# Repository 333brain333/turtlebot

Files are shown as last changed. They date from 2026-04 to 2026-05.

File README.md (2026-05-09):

# Turtlebot

|**Общий вид**|**Внутри робота**|**Вид снизу**|
|---|---|---|
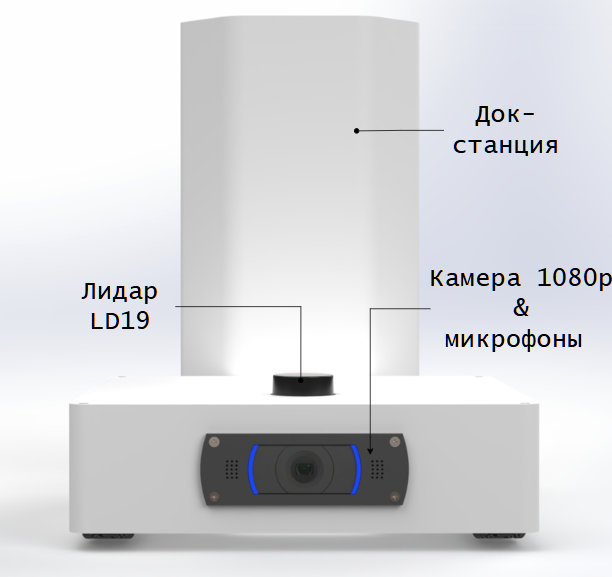
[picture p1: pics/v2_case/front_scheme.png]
Robot front view
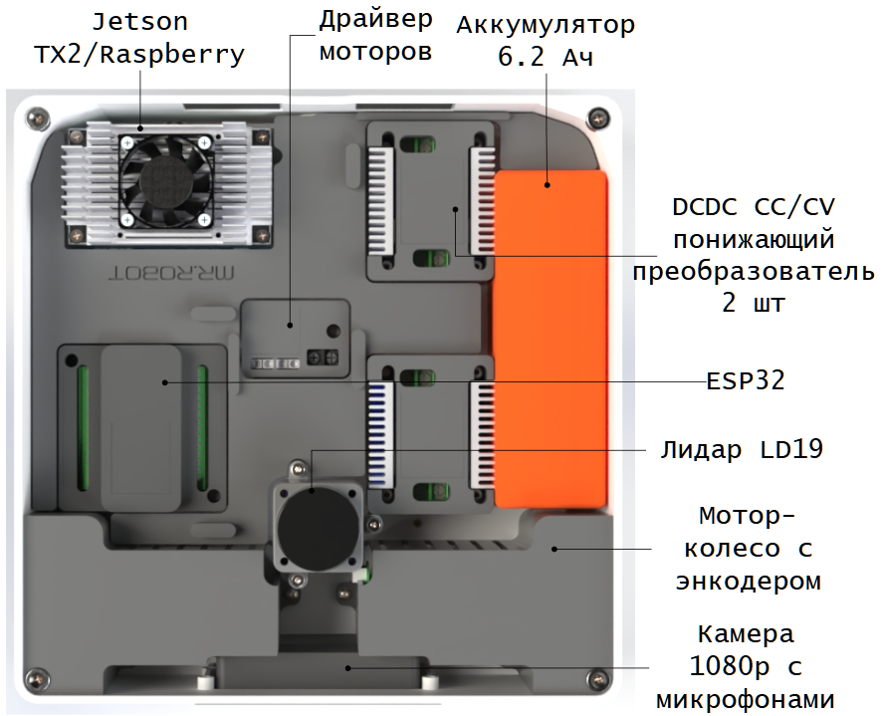
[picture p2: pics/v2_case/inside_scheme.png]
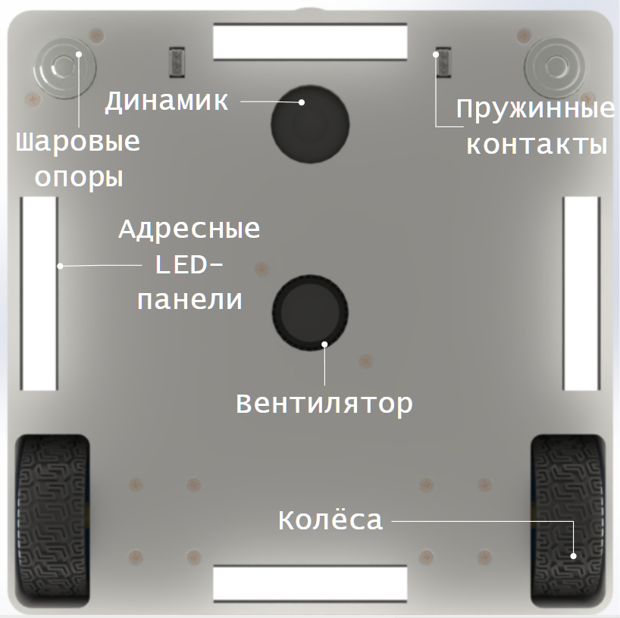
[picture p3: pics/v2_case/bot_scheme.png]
||||

Разработка 2х колёсного робота по типу turtlebot. [В рамках курса ROS2 — Введение в робототехнику](https://stepik.org/course/221157/promo#toc)  

# Wiki
В [Wiki](https://github.com/333brain333/turtlebot/wiki) репозитория находятся схемы соединения, перечень компонентов, 3D модели, etc.

(https://333brain333.github.io/turtle-rex-runner/)

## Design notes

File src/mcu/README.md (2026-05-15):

# MCU UART2 Interface

Описание интерфейса взаимодействия с микроконтроллером по UART2 на ESP32.

## Аппаратная часть

- UART: `Serial2`
- Baudrate: `115200`
- Формат: `8N1`
- RX: пин `16`
- TX: пин `17`
- Окончание команды: `\n` (перевод строки)

> Команды отправляются текстом, разделяя параметры пробелом.

При старте микроконтроллер дважды мигает адресной лентой: `0.5 с` включено, `0.5 с` выключено, `0.5 с` включено, затем оставляет ленту выключенной.

## Общая схема команды

Каждая команда начинается с ключевого слова и может содержать параметры:

```text
COMMAND_NAME param1 param2 ...
```

Пример:

```text
SET_LED 255 black
```

## Поддерживаемые команды

### `SET_PWM leftA leftB rightA rightB`

Управление ШИМ для моторов. Все значения в диапазоне `0..255`.

- `leftA` – ШИМ для `LEFT_MOTOR_A`
- `leftB` – ШИМ для `LEFT_MOTOR_B`
- `rightA` – ШИМ для `RIGHT_MOTOR_A`
- `rightB` – ШИМ для `RIGHT_MOTOR_B`

Пример:

```text
SET_PWM 0 200 0 200
```

### `SET_POSE x y theta`

Установить текущие координаты и угол робота.

- `x` – позиция по оси X
- `y` – позиция по оси Y
- `theta` – угол в радианах или градусах в зависимости от вашего применения

Пример:

```text
SET_POSE 10.5 20.0 1.57
```

### `SET_WHEELS_SPEED leftSpeed rightSpeed`

Задать целевую скорость колёс в мм/с.

- `leftSpeed` – целевая скорость левого колеса
- `rightSpeed` – целевая скорость правого колеса

Пример:

```text
SET_WHEELS_SPEED 100 100
```

### `SET_COEFF Kp Ki Kd Kff`

Обновить PID‑коэффициенты для регулировки скорости.

- `Kp` – пропорциональный
- `Ki` – интегральный
- `Kd` – дифференциальный
- `Kff` – форвард-фидбек

Пример:

```text
SET_COEFF 1.2 1.4 0.02 0.3
```

### `SET_LED brightness color`

Управление светодиодной лентой по всей длине.

- `brightness` – яркость `0..255`
- `color` – название цвета

Поддерживаемые цвета:

- `black` / `off`
- `white`
- `red`
- `green`
- `blue`
- `yellow`
- `cyan`
- `magenta`
- `orange`
- `purple`

Пример:

```text
SET_LED 255 black
SET_LED 128 red
SET_LED 200 blue
```

### `SHUTDOWN`

Выключить светодиодную ленту и отключить дальнейшую подачу ШИМ на драйвер колёс до перезапуска микроконтроллера.

Пример:

```text
SHUTDOWN
```

Ответ:

```text
OK: Shutdown
```

### `I2C_SCAN`

Вывести найденные I2C-адреса. Полезно для проверки INA226 на шине.

Пример:

```text
I2C_SCAN
```

Примеры ответов:

```text
I2C_SCAN 0x40
I2C_SCAN none
```

Для INA226 обычно ожидается адрес `0x40`.

### `INA226_DEBUG`

Вывести состояние INA226 и сырые значения основных регистров.

Пример:

```text
INA226_DEBUG
```

Пример ответа:

```text
INA226_DEBUG sda=21 scl=22 addr=0x40 available=1 probe_0x40=0 cfg=1:0x4527 bus=1:9876 shunt=1:120 mfg=1:0x5449 die=1:0x2260
```

Полезные поля:

- `sda` / `scl` — пины I2C на ESP32
- `available` — найден ли INA226 прошивкой
- `probe_0x40=0` — устройство ответило на адрес `0x40`
- `probe_0x40=2` — устройство не ответило на адрес `0x40`
- `bus` — сырое значение регистра напряжения
- `shunt` — сырое значение регистра шунта

## Ответы от микроконтроллера

Устройство отвечает строками вида:

- `OK: ...` — команда принята и выполнена
- `ERROR: ...` — команда неправильно сформирована или неизвестна

Примеры:

```text
OK: LED updated
ERROR: Unknown command
```

## Текущая телеметрия

Каждые ~100 мс микроконтроллер отправляет статус:

```text
POS X=... Y=... Th=... ENC L=... R=... SPD L=... mm/s R=... mm/s PWR V=... I=... A
```

Это полезно для отладки положения, энкодеров, скорости, напряжения и тока питания.

Поля питания:

- `PWR V` — напряжение шины, измеренное INA226, в вольтах
- `PWR I` — ток через шунт `0.01 Ом`, в амперах
- `PWR V=nan I=nan` — INA226 не найден или чтение по I2C не удалось

## Советы

- Отправляйте команды с `\n` в конце.
- Лучше сначала проверить ответ `OK`.
- Если команда возвращает `ERROR`, проверьте пробелы и порядок параметров.

## Быстрый пример взаимодействия

```text
SET_LED 255 blue
SET_WHEELS_SPEED 120 120
SET_COEFF 1.1 1.3 0.01 0.25
```

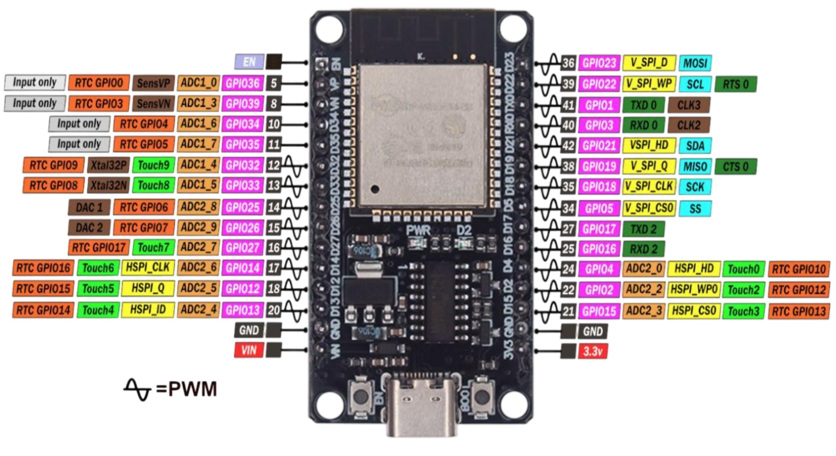
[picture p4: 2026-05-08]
pics/devices/esp32_pinout.jpg

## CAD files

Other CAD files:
3d_models/turtlebot_tx2.SLDASM
3d_models/turtlebot_nx.SLDASM

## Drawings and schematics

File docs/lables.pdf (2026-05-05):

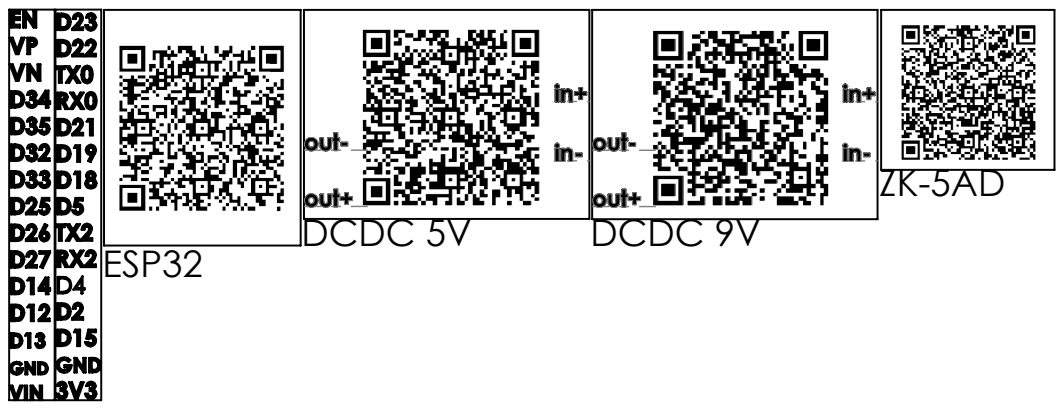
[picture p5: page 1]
DCDC 5V; DCDC 9V; МАСШТАБ:2:1; ЛИСТ 1 ИЗ 1; НЕ МАСШТАБИРОВАТЬ ЧЕРТЕЖ; РЕДАКЦИЯ; ЗАУСЕНЦЫ И ОСТРЫЕ КРОМКИ; ПО УМОЛЧАНИЮ:; ОБРАБОТКА:; РАЗМЕРЫ В МИЛЛИМЕТРАХ

ИМЯ | ПОДПИСЬ | ДАТА | | | | НАЗВАНИЕ:
Т.контр | | | | МАТЕРИАЛ: | ЧЕРТЕЖ №: этикетки МАССА: | A4

Разраб.
Пров.
Утв.
Маш.

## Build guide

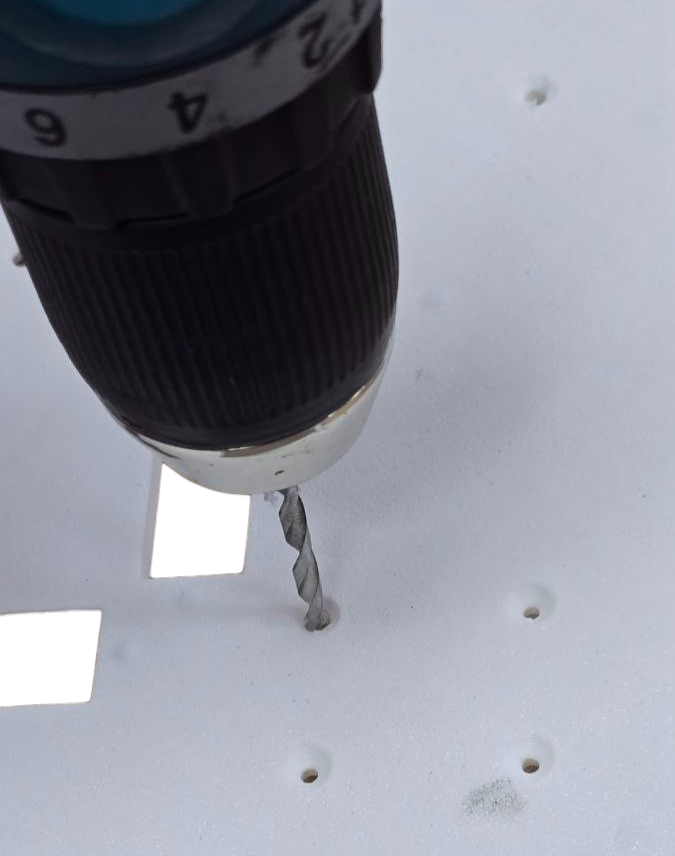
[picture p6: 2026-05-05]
pics/v2_case/assembly/drill.png

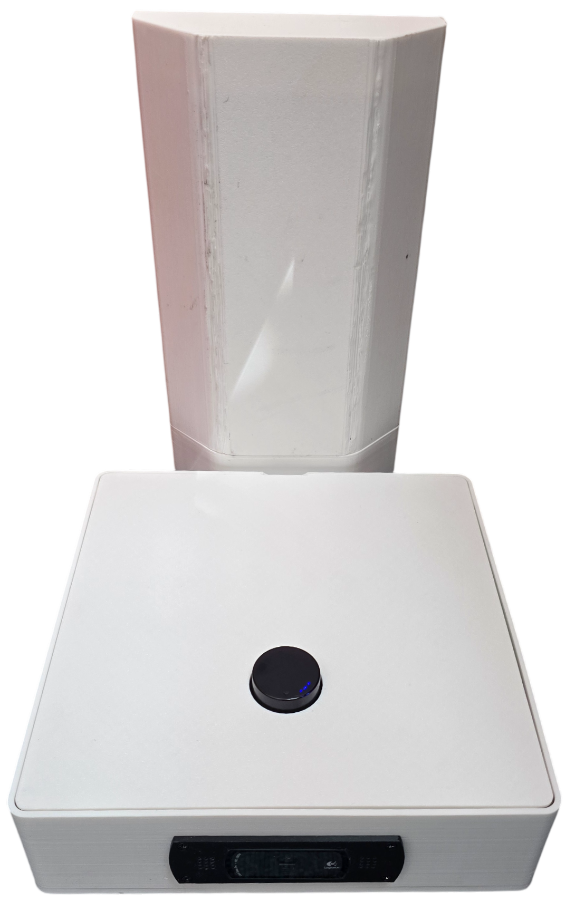
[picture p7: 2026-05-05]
pics/v2_case/assembly/doc_front.png

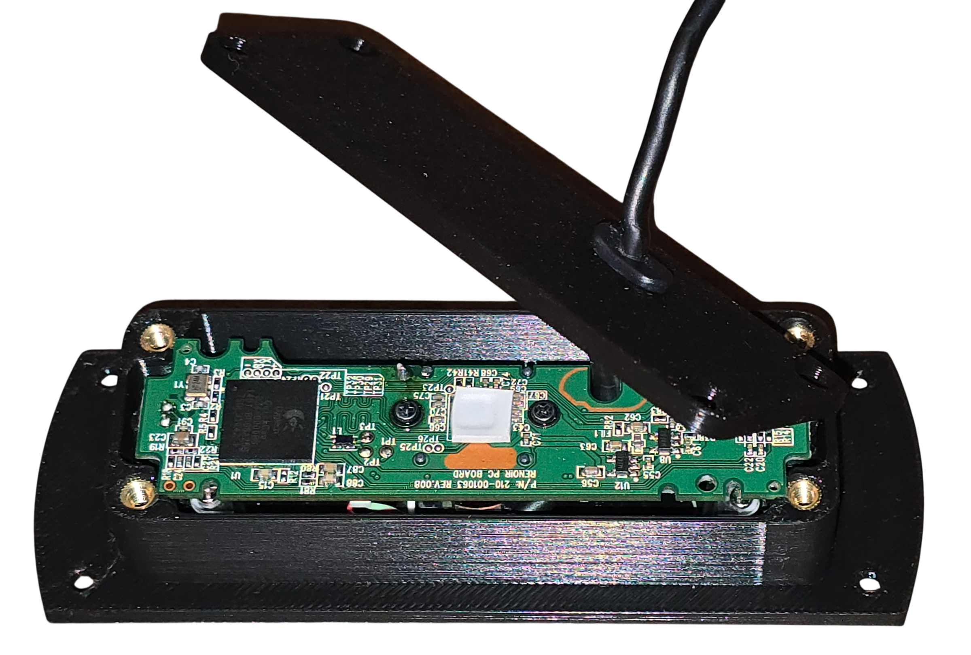
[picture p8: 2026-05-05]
pics/v2_case/assembly/cam_.png

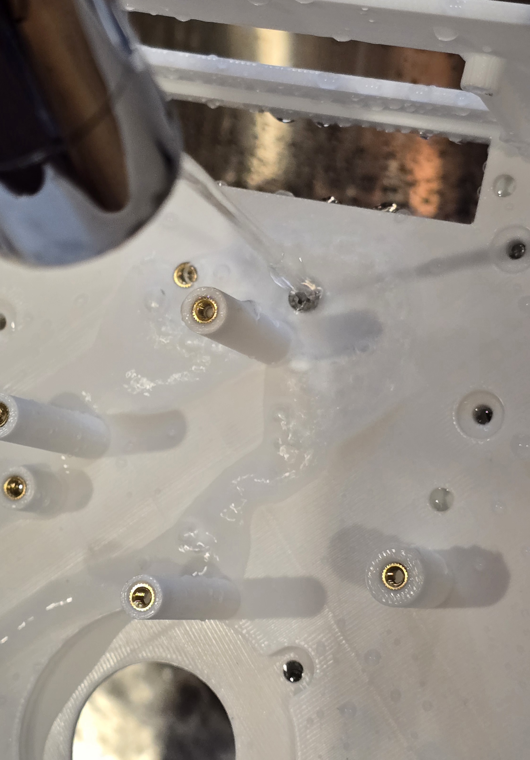
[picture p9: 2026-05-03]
pics/v2_case/assembly/cool.jpg

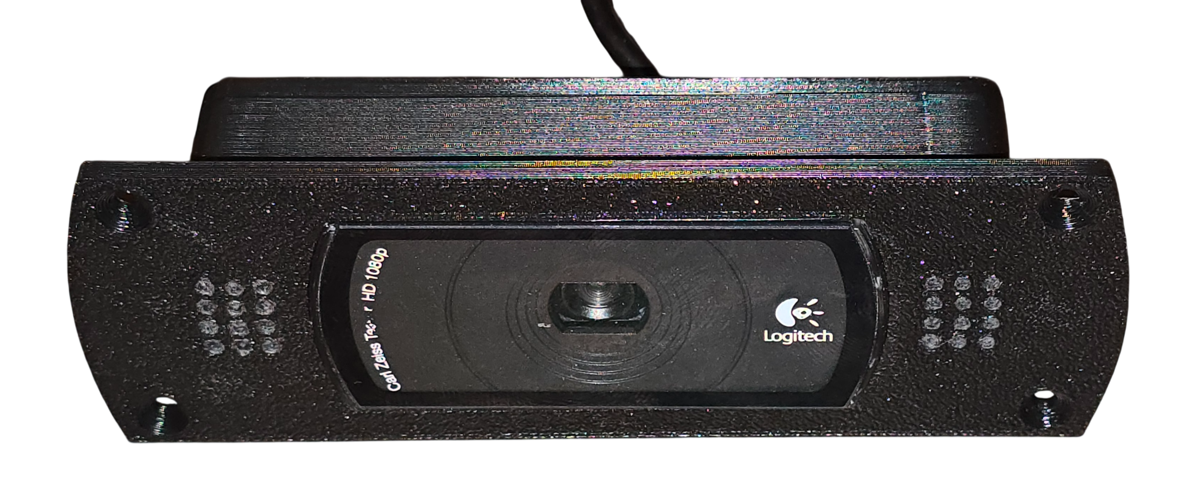
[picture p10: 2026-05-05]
pics/v2_case/assembly/cam_ass.png

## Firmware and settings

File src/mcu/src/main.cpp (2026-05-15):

#include <Arduino.h>
#include "main.h"
#include <FastLED.h>
#include <Wire.h>

#define LED_STRIP_PIN 13       // Пин подключения ленты к ESP32
#define NUM_LEDS    32          // Количество светодиодов в ленте
#define BRIGHTNESS  255          // Яркость (0-255)
#define LED_TYPE    WS2812B     // Тип светодиодной ленты
#define COLOR_ORDER GRB         // Порядок цветов (для WS2812B обычно GRB)

#define LEFT_MOTOR_A 14     // Цифровой выход (левый мотор). Если 0 - едем вперед
#define LEFT_MOTOR_B 27     // Цифровой выход (левый мотор). Если 0 - едем назад
#define RIGHT_MOTOR_A 25    // Цифровой выход (правый мотор). Если 0 - едем вперед
#define RIGHT_MOTOR_B 26    // Цифровой выход (правый мотор). Если 0 - едем назад

#define LED_BUILTIN_PIN 2       // Встроенный светодиод на ESP32 Dev Board

#define LEFT_ENCODER_A 33    // Цифровой вход, канал A энкодера левого колеса
#define LEFT_ENCODER_B 32    // Цифровой вход, канал B энкодера левого колеса 
#define RIGHT_ENCODER_A 34   // Цифровой вход, канал A энкодера правого колеса
#define RIGHT_ENCODER_B 35   // Цифровой вход, канал B энкодера правого колеса

#define JETSON_UART_RX 16     // RX2: прием данных от Jetson TX
#define JETSON_UART_TX 17     // TX2: передача данных на Jetson RX
#define JETSON_UART_BAUD 115200


/*
  * Константы для работы с INA226:
  * - INA226_I2C_SDA и INA226_I2C_SCL определяют пины для I2C шины, к которой подключён датчик.
  * - INA226_I2C_ADDRESS — стандартный адрес устройства на шине I2C (может быть изменён в зависимости от конкретной платы).
  * - INA226_SHUNT_OHMS — сопротивление шунта в Омах, используемое для расчёта тока по измеренному напряжению на шунте.
  *
  * Регистры:
  * - INA226_REG_CONFIG — регистр конфигурации, который нужно настроить для правильной работы датчика.
  * - INA226_REG_SHUNT_VOLTAGE — регистр, в котором хранится измеренное напряжение на шунте (для расчёта тока).
  * - INA226_REG_BUS_VOLTAGE — регистр, в котором хранится измеренное напряжение питания (для расчёта мощности).
  * - INA226_REG_MANUFACTURER_ID и INA226_REG_DIE_ID — служебные регистры для идентификации устройства.
*/
#define INA226_I2C_SDA 21
#define INA226_I2C_SCL 22
#define INA226_I2C_ADDRESS 0x40
#define INA226_SHUNT_OHMS 0.01f

#define INA226_REG_CONFIG 0x00
#define INA226_REG_SHUNT_VOLTAGE 0x01
#define INA226_REG_BUS_VOLTAGE 0x02
#define INA226_REG_MANUFACTURER_ID 0xFE
#define INA226_REG_DIE_ID 0xFF

/**
 * Глобальные переменные для хранения текущего счёта тиков (импульсов) энкодеров.
 * Используется тип long, т.к. значения могут быть достаточно большими при длительной работе.
 * Ключевое слово volatile указывает, что данные могут изменяться асинхронно (в прерываниях).
 */
volatile long left_encoder_value = 0; 
volatile long right_encoder_value = 0;

/**
 * Переменные для харения состоания скорости колёс и одометрии
 */
long last_left_encoder = 0;
long last_right_encoder = 0;

long last_speed_left_encoder = 0, last_speed_right_encoder = 0;
float leftWheelSpeed = 0.0, rightWheelSpeed = 0.0;
float vlSpeedFiltered = 0.0, vrSpeedFiltered = 0.0;
uint32_t lastTimeL = 0, lastTimeR = 0;

float targetLeftWheelSpeed = 0, targetRightWheelSpeed = 0;

float xPos = 0.0, yPos = 0.0, theta = 0.0;

const float WHEEL_DIAMETER = 68.0; // Укажите ваш диаметр колёс
const float WHEEL_BASE = 212.94; // Укажите ваще расстояние между колёсами
const float ENCODER_RESOLUTION = 330.0;
const float TICKS_TO_MM = (PI * WHEEL_DIAMETER) / ENCODER_RESOLUTION;
const float ALPHA = 0.2; // Коэффициент фильтрации скорости

// Глобальные коэффициенты PID – их можно обновлять через UART
float pidKp = 1.1;
float pidKi = 1.3;
float pidKd = 0.01;
float pidKff = 0.25;

// Глобальные PID-состояния
float errorLeftIntegral = 0;
float errorRightIntegral = 0;
float prevErrorLeft = 0;
float prevErrorRight = 0;
uint32_t lastPIDTime = 0;

/**
 * Переменные для настройки моргания светодиодом на плате
 */
bool led_state = false;
unsigned long previous_led_millis = 0;
const unsigned long LED_BLINK_INTERVAL_MS = 500;


/**
 * Обработчики прерываний для энкодеров:
 * - left_interrupt() изменяет счётчик левого энкодера в зависимости от состояния второго канала (LEFT_ENCODER_B).
 * - right_interrupt() аналогично обрабатывает импульсы правого энкодера, используя RIGHT_ENCODER_B.
 *
 * Логика:
 *   Если на втором канале энкодера HIGH — увеличиваем счётчик, иначе уменьшаем.
 *   Это классический способ определения направления вращения по двум каналам энкодера.
 */
void left_interrupt() {digitalRead(LEFT_ENCODER_B)?left_encoder_value++:left_encoder_value--;}
void right_interrupt() {digitalRead(RIGHT_ENCODER_B)?right_encoder_value++:right_encoder_value--;}


/****************************************************************************
 * Переменные компенсации прямолинейного движения
 ***************************************************************************/
bool goingStraight = false;  // Флаг, указывающий, что робот едет прямо (угловая скорость ≈ 0)
long leftBase = 0;           // Значение left_encoder_value в момент начала прямолинейного движения
long rightBase = 0;          // Значение right_encoder_value в момент начала прямолинейного движения

/*
 * Для светодиодной ленты FastLED, мы создаём 
 * глобальный массив типа CRGB, который будет хранить цвет каждого светодиода.
*/
CRGB leds[NUM_LEDS];
uint8_t currentLedBrightness = BRIGHTNESS;
CRGB currentLedColor = CRGB::White;
bool ledsNeedUpdate = true;

bool ina226Available = false;
uint8_t ina226Address = INA226_I2C_ADDRESS;
float ina226BusVoltage = 0.0f;
float ina226Current = 0.0f;
bool motorDriverEnabled = true;


/**
 * SETUP
 */
void setup() {
  Serial2.begin(JETSON_UART_BAUD, SERIAL_8N1, JETSON_UART_RX, JETSON_UART_TX);
  delay(1000);
  Serial2.println("System started");

  pinMode(INA226_I2C_SDA, INPUT_PULLUP);
  pinMode(INA226_I2C_SCL, INPUT_PULLUP);
  Wire.begin(INA226_I2C_SDA, INA226_I2C_SCL);
  Wire.setClock(100000);
  Wire.setTimeOut(50);
  ina226Available = initIna226();
  if (ina226Available) {
    Serial2.printf("INA226 started addr=0x%02X\r\n", ina226Address);
  } else {
    Serial2.println("INA226 not found");
  }

  // Инициализация ленты с указанием пина, типа и массива светодиодов
  FastLED.addLeds<LED_TYPE, LED_STRIP_PIN, COLOR_ORDER>(leds, NUM_LEDS).setCorrection(TypicalLEDStrip);
  blinkLedStripOnStartup();

  /**
   * Подключение функций-прерываний (interrupt service routines, ISR) к выводам энкодеров.
   * digitalPinToInterrupt(ПИН) преобразует номер пина в номер прерывания, которое мы хотим отлавливать.
   * Событие RISING означает вызов прерывания при переходе сигнала с LOW на HIGH.
   */
  attachInterrupt(digitalPinToInterrupt(LEFT_ENCODER_A), left_interrupt, RISING);
  attachInterrupt(digitalPinToInterrupt(RIGHT_ENCODER_A), right_interrupt, RISING);
  
  // Настройка выводов для управления моторами как выходы (OUTPUT).
  pinMode(LEFT_MOTOR_A,OUTPUT);
  pinMode(LEFT_MOTOR_B,OUTPUT);
  pinMode(RIGHT_MOTOR_A,OUTPUT);
  pinMode(RIGHT_MOTOR_B,OUTPUT);
  pinMode(LED_BUILTIN_PIN, OUTPUT);
  
  // Настройка выводов энкодеров как входы (INPUT).
  pinMode(LEFT_ENCODER_A, INPUT);
  pinMode(LEFT_ENCODER_B, INPUT);
  pinMode(RIGHT_ENCODER_A, INPUT);
  pinMode(RIGHT_ENCODER_B, INPUT);
  
  /**
   * Настройка сигналов для управления скоростью и направлением вращения:
   *   - analogWrite(LEFT_MOTOR_A, 0) и analogWrite(LEFT_MOTOR_B, 100) задают движение левого мотора "вперед"
   *     (поскольку один вывод на 0, второй на некий уровень ШИМ).
   *   - analogWrite(RIGHT_MOTOR_A, 0) и analogWrite(RIGHT_MOTOR_B, 100) аналогично для правого мотора.
   *
   * В зависимости от используемой библиотеки и типа контроллера, analogWrite может включать ШИМ (PWM).
   * Значение 0 = 0% скважности, 255 = 100% (может зависеть от конкретной платформы).
   */
  // analogWrite(LEFT_MOTOR_A,0);
  // analogWrite(LEFT_MOTOR_B,255); 
  // analogWrite(RIGHT_MOTOR_A,0);
  // analogWrite(RIGHT_MOTOR_B,255);
}

/**
 * LOOP
 */
void loop() {
  // Блок для моргания встроенным светодиодом на плате ESP32 каждые 500 мс, чтобы показать, что система работает.
  unsigned long current_millis = millis();
  if (current_millis - previous_led_millis >= LED_BLINK_INTERVAL_MS) {
    previous_led_millis = current_millis;
    led_state = !led_state;
    digitalWrite(LED_BUILTIN_PIN, led_state ? HIGH : LOW);
  }
  if (ledsNeedUpdate) {
    FastLED.setBrightness(currentLedBrightness);
    fill_solid(leds, NUM_LEDS, currentLedColor);
    FastLED.show();
    ledsNeedUpdate = false;
  }

  if (Serial2.available()) {
    String command = Serial2.readStringUntil('\n');
    processCommand(command);
  }
  static uint32_t PIDTimer = 0;
  if (millis() - PIDTimer > 50) {
    computeSpeed();
    updateOdometry();
    computeWheelsPID();
    updateIna226();
    PIDTimer = millis();
  }

  static uint32_t printTimer = 0;
  if (millis() - printTimer > 100){
    Serial2.printf("POS X=%.2f Y=%.2f Th=%.2f ", xPos, yPos, theta);
    Serial2.printf("ENC L=%ld R=%ld ", left_encoder_value, right_encoder_value);
    Serial2.printf("SPD L=%.2f mm/s R=%.2f mm/s ", vlSpeedFiltered, vrSpeedFiltered);
    if (ina226Available) {
      Serial2.printf("PWR V=%.3f I=%.3f A\r\n", ina226BusVoltage, ina226Current);
    } else {
      Serial2.print("PWR V=nan I=nan A\r\n");
    }
    printTimer = millis();
  }

  static uint32_t ina226RetryTimer = 0;
  if (!ina226Available && millis() - ina226RetryTimer > 1000) {
    ina226Available = initIna226();
    if (ina226Available) {
      Serial2.printf("INA226 started addr=0x%02X\r\n", ina226Address);
    }
    ina226RetryTimer = millis();
  }
}

void processCommand(String command) {
  command.trim();
  if (command.startsWith("SET_PWM")) {
    int leftA_PWM = 0, leftB_PWM = 0, rightA_PWM =0, rightB_PWM = 0;
    if (parseSetPWM(command, &leftA_PWM, &leftB_PWM, &rightA_PWM, &rightB_PWM)) {
      setMotorsPWM(leftA_PWM, leftB_PWM, rightA_PWM, rightB_PWM);
      Serial2.print("OK: Set PWM");
    }
    return;
  } else if (command.startsWith("SET_POSE")) {
    float x, y, th;
    if (parseSetPose(command, &x, &y, &th)) {
      xPos = x;
      yPos = y;
      theta = th;
      Serial2.println("OK: Pose set");
    }
  } else if (command.startsWith("SET_WHEELS_SPEED")) {
    int leftSpeed = 0, rightSpeed = 0;
    if (parseSetSpeed(command, &leftSpeed, &rightSpeed)) {
      targetLeftWheelSpeed = leftSpeed;
      targetRightWheelSpeed = rightSpeed;
      Serial2.println("OK: Wheel speed set");
    }
  } else if (command.startsWith("SET_COEFF")) {
    float newKp, newKi, newKd, newKff;
    if (parseSetCoeff(command, &newKp, &newKi, &newKd, &newKff)) {
      pidKp = newKp;
      pidKi = newKi;
      pidKd = newKd;
      pidKff = newKff;
      Serial2.println("OK: Coefficients updated");
    } else {
      Serial2.println("ERROR: Invalid coefficients");
    }
  } else if (command.startsWith("SET_LED")) {
    int brightness = 0;
    String colorName;
    if (parseSetLed(command, &brightness, &colorName)) {
      CRGB parsedColor;
      if (parseColorName(colorName, &parsedColor)) {
        currentLedBrightness = constrain(brightness, 0, 255);
        currentLedColor = parsedColor;
        ledsNeedUpdate = true;
        Serial2.println("OK: LED updated");
      } else {
        Serial2.println("ERROR: Unknown color");
      }
    } else {
      Serial2.println("ERROR: Invalid SET_LED format");
    }
  } else if (command.startsWith("SET_ROBOT_VELOCITY")) {
    float linVel = 0.0, angVel = 0.0;
    if (parseSetRobotVelocity(command, &linVel, &angVel)) {
      setRobotVelocity(linVel, angVel);
      Serial2.println("OK: Robot velocity set");
    } else {
      Serial2.println("ERROR: Invalid robot velocity command");
    }
  } else if (command == "SHUTDOWN") {
    shutdownSystem();
    Serial2.println("OK: Shutdown");
  } else if (command == "I2C_SCAN") {
    scanI2cBus();
  } else if (command == "INA226_DEBUG") {
    printIna226Debug();
  } else {
    Serial2.println("ERROR: Unknown command");
  }
}

bool parseSetPose(const String& command, float* x, float* y, float* th) {
  int index1 = command.indexOf(' ');
  if (index1 == -1) return false;
  int index2 = command.indexOf(' ', index1 + 1);
  if (index2 == -1) return false;
  int index3 = command.indexOf(' ', index2 + 1);
  if (index3 == -1) return false;
  
  *x = command.substring(index1 + 1, index2).toFloat();
  *y = command.substring(index2 + 1, index3).toFloat();
  *th = command.substring(index3 + 1).toFloat();
  return true;
}

bool parseSetPWM(const String& command, int* leftA_PWM, int* leftB_PWM, int* rightA_PWM, int* rightB_PWM) {
  int index1 = command.indexOf(' ');
  if (index1 == -1) return false;
  int index2 = command.indexOf(' ', index1 + 1);
  if (index2 == -1) return false;
  int index3 = command.indexOf(' ', index2 + 1);
  if (index3 == -1) return false;
  int index4 = command.indexOf(' ', index3 + 1);
  if (index4 == -1) return false;

  *leftA_PWM = command.substring(index1 + 1, index2).toInt();
  *leftB_PWM = command.substring(index2 + 1, index3).toInt();
  *rightA_PWM = command.substring(index3 + 1, index4).toInt();
  *rightB_PWM = command.substring(index4 + 1).toInt();
  return true;
}


void setMotorsPWM(int leftA, int leftB, int rightA, int rightB) {
  if (!motorDriverEnabled) {
    analogWrite(LEFT_MOTOR_A, 0);
    analogWrite(LEFT_MOTOR_B, 0);
    analogWrite(RIGHT_MOTOR_A, 0);
    analogWrite(RIGHT_MOTOR_B, 0);
    return;
  }

  leftA  = constrain(leftA, 0, 255);
  leftB  = constrain(leftB, 0, 255);
  rightA = constrain(rightA, 0, 255);
  rightB = constrain(rightB, 0, 255);

  analogWrite(LEFT_MOTOR_A,   leftA);
  analogWrite(LEFT_MOTOR_B,   leftB);
  analogWrite(RIGHT_MOTOR_A,  rightA);
  analogWrite(RIGHT_MOTOR_B,  rightB);
}

void shutdownSystem() {
  targetLeftWheelSpeed = 0;
  targetRightWheelSpeed = 0;
  motorDriverEnabled = false;
  setMotorsPWM(0, 0, 0, 0);

  currentLedBrightness = 0;
  currentLedColor = CRGB::Black;
  fill_solid(leds, NUM_LEDS, CRGB::Black);
  FastLED.setBrightness(0);
  FastLED.show();
  ledsNeedUpdate = false;
}

void blinkLedStripOnStartup() {
  FastLED.setBrightness(currentLedBrightness);

  fill_solid(leds, NUM_LEDS, currentLedColor);
  FastLED.show();
  delay(500);

  fill_solid(leds, NUM_LEDS, CRGB::Black);
  FastLED.show();
  delay(500);

  fill_solid(leds, NUM_LEDS, currentLedColor);
  FastLED.show();
  delay(500);

  currentLedBrightness = 0;
  currentLedColor = CRGB::Black;
  FastLED.setBrightness(currentLedBrightness);
  fill_solid(leds, NUM_LEDS, currentLedColor);
  FastLED.show();
  ledsNeedUpdate = false;
}

void updateOdometry() {
  long deltaLeft = left_encoder_value - last_left_encoder;
  long deltaRight = right_encoder_value - last_right_encoder;

  last_left_encoder = left_encoder_value;
  last_right_encoder = right_encoder_value;

  float distLeft = deltaLeft * TICKS_TO_MM;
  float distRight = deltaRight * TICKS_TO_MM;

  float deltaS = (distLeft + distRight) / 2.0;
  float deltaTheta = (distRight - distLeft) / WHEEL_BASE;

  xPos += deltaS * cos(theta + deltaTheta / 2.0);
  yPos += deltaS * sin(theta + deltaTheta / 2.0);

  theta += deltaTheta;
}

void computeSpeed() {
  uint32_t now = micros();

  if (lastTimeL == 0 || lastTimeR == 0) { // Первая инициализация таймера
    lastTimeL = now;
    lastTimeR = now;
    last_speed_left_encoder = left_encoder_value;
    last_speed_right_encoder = right_encoder_value;
    return;
  }

  float dtL = (now - lastTimeL) * 0.000001;
  float dtR = (now - lastTimeR) * 0.000001;

  if (dtL > 0 && left_encoder_value != last_speed_left_encoder) {
    long deltaLeft = left_encoder_value - last_speed_left_encoder;
    float wlSpeed = ((float)deltaLeft / ENCODER_RESOLUTION) * 360.0f / dtL;
    float vlSpeed = (wlSpeed / 360.0f) * (PI * WHEEL_DIAMETER);
    vlSpeedFiltered = ALPHA * vlSpeed + (1.0f - ALPHA) * vlSpeedFiltered;
    last_speed_left_encoder = left_encoder_value;
    lastTimeL = now;

    //Serial.printf("Left: ΔEnc=%ld, dt=%.6f, Speed=%.2f mm/s\n", deltaLeft, dtL, vlSpeedFiltered);
  } else if (dtL > 0.005 && left_encoder_value == last_speed_left_encoder){
    vlSpeedFiltered = 0;
  }

  if (dtR > 0 && right_encoder_value != last_speed_right_encoder) {
    long deltaRight = right_encoder_value - last_speed_right_encoder;
    float wrSpeed = ((float)deltaRight / ENCODER_RESOLUTION) * 360.0f / dtR;
    float vrSpeed = (wrSpeed / 360.0f) * (PI * WHEEL_DIAMETER);
    vrSpeedFiltered = ALPHA * vrSpeed + (1.0f - ALPHA) * vrSpeedFiltered;
    last_speed_right_encoder = right_encoder_value;
    lastTimeR = now;

    //Serial.printf("Right: ΔEnc=%ld, dt=%.6f, Speed=%.2f mm/s\n", deltaRight, dtR, vrSpeedFiltered);
  } else if (dtR > 0.005 && right_encoder_value == last_speed_right_encoder){
    vrSpeedFiltered = 0;
  }
}

void resetPID() {
  errorLeftIntegral = 0;
  errorRightIntegral = 0;
  prevErrorLeft = 0;
  prevErrorRight = 0;
  vlSpeedFiltered = 0;
  vrSpeedFiltered = 0;
  lastPIDTime = millis();
}

void computeWheelsPID(){
  if (!motorDriverEnabled) {
    setMotorsPWM(0, 0, 0, 0);
    return;
  }

  // Ограничение интегральной составляющей (anti-windup)
  const float integralLimit = 100.0;

  // Для сброса интегральной составляющей при смене целевой скорости
  static float lastTargetLeft = 0.0;
  static float lastTargetRight = 0.0;

  // Сброс интеграла, если целевая скорость изменилась
  if(targetLeftWheelSpeed != lastTargetLeft){
    // resetPID();
    errorLeftIntegral = 0;
    prevErrorLeft = 0;
    lastTargetLeft = targetLeftWheelSpeed;
  }
  if(targetRightWheelSpeed != lastTargetRight){
    // resetPID();
    errorRightIntegral = 0;
    prevErrorRight = 0;
    lastTargetRight = targetRightWheelSpeed;
  }
  if (targetLeftWheelSpeed == 0 && targetRightWheelSpeed == 0) {
    resetPID();
  }

  // Вычисляем интервал dt (в секундах)
  uint32_t now = millis();
  float dt = (now - lastPIDTime) / 1000.0f;
  if(dt < 0.001f) dt = 0.001f;
  lastPIDTime = now;

  // Расчет ошибок
  float errorLeft  = targetLeftWheelSpeed  - vlSpeedFiltered;
  float errorRight = targetRightWheelSpeed - vrSpeedFiltered;

  // Интегральная составляющая
  errorLeftIntegral  += errorLeft  * dt;
  errorRightIntegral += errorRight * dt;
  if(errorLeftIntegral > integralLimit)  errorLeftIntegral  = integralLimit;
  if(errorLeftIntegral < -integralLimit) errorLeftIntegral  = -integralLimit;
  if(errorRightIntegral > integralLimit)  errorRightIntegral = integralLimit;
  if(errorRightIntegral < -integralLimit) errorRightIntegral = -integralLimit;

  // Производная ошибки
  float derivativeLeft  = (errorLeft  - prevErrorLeft)  / dt;
  float derivativeRight = (errorRight - prevErrorRight) / dt;
  prevErrorLeft  = errorLeft;
  prevErrorRight = errorRight;

  // Вычисление PID-выхода с использованием глобальных коэффициентов
  float pidLeft  = pidKp * errorLeft  + pidKi * errorLeftIntegral  + pidKd * derivativeLeft;
  float pidRight = pidKp * errorRight + pidKi * errorRightIntegral + pidKd * derivativeRight;

  // Добавляем feedforward
  float outputLeft  = pidLeft  + pidKff * targetLeftWheelSpeed;
  float outputRight = pidRight + pidKff * targetRightWheelSpeed;

  // --- Компенсация прямолинейного движения ---
  if (goingStraight && fabs(targetLeftWheelSpeed) > 1.0 && fabs(targetRightWheelSpeed) > 1.0) {
    // Вычисляем накопленное смещение от базового значения, зафиксированного при старте прямолинейного движения
    long leftTicks  = left_encoder_value - leftBase;
    long rightTicks = right_encoder_value - rightBase;
    long diff = leftTicks - rightTicks;  // если diff > 0, левое колесо продвинулось дальше
    float KencStraight = 3.0f;  // Подберите опытным путём
    float corr = KencStraight * (float)diff;
    // Применяем корректировку: по 50% для каждого колеса
    outputLeft  -= corr * 0.5f;
    outputRight += corr * 0.5f;
  }
  // --- Конец компенсации ---

  // Преобразование в значения ШИМ
  int leftA_PWM = 0, leftB_PWM = 0;
  int rightA_PWM = 0, rightB_PWM = 0;

  if(outputLeft >= 0){
    leftA_PWM = 0;
    leftB_PWM = constrain((int)outputLeft, 0, 255);
  } else {
    leftA_PWM = constrain((int)(-outputLeft), 0, 255);
    leftB_PWM = 0;
  }
  if(outputRight >= 0){
    rightA_PWM = 0;
    rightB_PWM = constrain((int)outputRight, 0, 255);
  } else {
    rightA_PWM = constrain((int)(-outputRight), 0, 255);
    rightB_PWM = 0;
  }

  setMotorsPWM(leftA_PWM, leftB_PWM, rightA_PWM, rightB_PWM);
}

bool initIna226() {
  if (!findIna226()) {
    return false;
  }

  // AVG=16, VBUSCT=1.1 ms, VSHCT=1.1 ms, continuous shunt+bus mode.
  return writeIna226Register(INA226_REG_CONFIG, 0x4527);
}

bool findIna226() {
  uint8_t firstRespondingAddress = 0;

  for (uint8_t address = 0x40; address <= 0x4F; address++) {
    Wire.beginTransmission(address);
    if (Wire.endTransmission() != 0) {
      continue;
    }

    if (firstRespondingAddress == 0) {
      firstRespondingAddress = address;
    }

    ina226Address = address;
    uint16_t manufacturerId = 0;
    uint16_t dieId = 0;
    if (readIna226Register(INA226_REG_MANUFACTURER_ID, &manufacturerId) &&
        readIna226Register(INA226_REG_DIE_ID, &dieId) &&
        manufacturerId == 0x5449 &&
        (dieId & 0xFFF0) == 0x2260) {
      return true;
    }
  }

  if (firstRespondingAddress != 0) {
    ina226Address = firstRespondingAddress;
    return true;
  }

  ina226Address = INA226_I2C_ADDRESS;
  return false;
}

void updateIna226() {
  if (!ina226Available) {
    return;
  }

  uint16_t busRaw = 0;
  uint16_t shuntRaw = 0;
  if (!readIna226Register(INA226_REG_BUS_VOLTAGE, &busRaw) ||
      !readIna226Register(INA226_REG_SHUNT_VOLTAGE, &shuntRaw)) {
    ina226Available = false;
    return;
  }

  ina226BusVoltage = busRaw * 0.00125f;
  const float shuntVoltage = (int16_t)shuntRaw * 0.0000025f;
  ina226Current = shuntVoltage / INA226_SHUNT_OHMS;
}
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

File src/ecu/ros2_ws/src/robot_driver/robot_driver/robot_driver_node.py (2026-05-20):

#!/usr/bin/env python3

import rclpy
from rclpy.node import Node

from geometry_msgs.msg import Pose2D, Twist
from nav_msgs.msg import Odometry
from geometry_msgs.msg import TransformStamped
from std_msgs.msg import String

import tf2_ros
import serial
import re
from transforms3d.euler import euler2quat


class RobotDriverNode(Node):
    def __init__(self):
        super().__init__("robot_driver_node")

        # 1. Подписка на /cmd_vel для приёма скоростей
        self.cmd_vel_sub = self.create_subscription(
            Twist, "/cmd_vel", self.cmd_vel_callback, 10
        )
        self.set_pose_sub = self.create_subscription(
            Pose2D, "/set_pose", self.set_pose_callback, 10
        )
        self.set_led_sub = self.create_subscription(
            String, "/SET_LED", self.set_led_callback, 10
        )
        self.shutdown_sub = self.create_subscription(
            String, "/SHUTDOWN", self.shutdown_callback, 10
        )
        self.set_coeff_sub = self.create_subscription(
            String, "/SET_COEFF", self.set_coeff_callback, 10
        )

        # 2. Паблишер одометрии
        self.odom_pub = self.create_publisher(Odometry, "/odom", 10)
        self.raw_esp32_pub = self.create_publisher(String, "/ESP32_RAW", 50)

        # 3. TF Broadcaster
        self.tf_broadcaster = tf2_ros.TransformBroadcaster(self)

        # 4. Открываем Serial-порт
        serial_port_path = "/dev/ttyTHS2"
        self.ser = serial.Serial(serial_port_path, baudrate=115200, timeout=0.1)
        self.get_logger().info(f"Opened serial port: {serial_port_path}")

        # 5. Регулярка для парсинга строк вида: "POS X=120.00 Y=150.00 Th=0.45"
        self.pos_pattern = re.compile(r"POS X=([\-\d\.]+) Y=([\-\d\.]+) Th=([\-\d\.]+)")

        # 6. Периодический таймер для чтения данных из Serial
        self.timer_period = 0.05  # 20 Гц
        self.read_serial_timer = self.create_timer(
            self.timer_period, self.read_serial_timer_callback
        )

    def write_serial_command(self, command: str):
        command = command.strip()
        if not command:
            return
        try:
            self.ser.write((command + "\n").encode("utf-8"))
            self.get_logger().info(f"Sent command: {command}")
        except serial.SerialException as e:
            self.get_logger().error(f"Failed to write to serial: {e}")

    def set_pose_callback(self, msg: Pose2D):
        x = msg.x * 1000
        y = msg.y * 1000
        command = f"SET_POSE {x:.2f} {y:.2f} {msg.theta:.2f}\n"
        self.write_serial_command(command)

    def cmd_vel_callback(self, msg: Twist):
        """
        Колбэк, вызывается при приходе сообщения в /cmd_vel
        Отправляем команду скорости на ESP32 по Serial.
        """
        linear_velocity = msg.linear.x * 1000.0  # м/с -> мм/с
        angular_velocity = msg.angular.z  # рад/с

        command = f"SET_ROBOT_VELOCITY {linear_velocity:.2f} {angular_velocity:.2f}\n"
        self.write_serial_command(command)

    def set_led_callback(self, msg: String):
        self.write_serial_command(msg.data)

    def shutdown_callback(self, msg: String):
        self.write_serial_command(msg.data or "SHUTDOWN")

    def set_coeff_callback(self, msg: String):
        self.write_serial_command(msg.data)

    def read_serial_timer_callback(self):
        """
        Периодически читаем строки из Serial.
        Если строка похожа на POS X=... Y=... Th=..., парсим и публикуем одометрию + TF.
        """
        # Считываем всё, что накопилось в буфере (т.к. timeout=0.1)
        try:
            # Можем читать построчно, т.к. ESP32 шлёт строки.
            line = self.ser.readline().decode("ascii", errors="ignore").strip()

            if not line:
                return  # нет данных в данный момент

            self.raw_esp32_pub.publish(String(data=line))

            # Проверим, похоже ли это на строку одометрии
            match = self.pos_pattern.search(line)
            if match:
                x_mm = float(match.group(1))  # мм
                y_mm = float(match.group(2))  # мм
                th = float(match.group(3))  # рад

                # Переводим мм -> м
                x = x_mm / 1000.0
                y = y_mm / 1000.0

                # Формируем Odometry
                odom_msg = Odometry()
                odom_msg.header.stamp = self.get_clock().now().to_msg()
                odom_msg.header.frame_id = "odom"
                odom_msg.child_frame_id = "base_link"

                odom_msg.pose.pose.position.x = x
                odom_msg.pose.pose.position.y = y
                odom_msg.pose.pose.position.z = 0.0

                # Преобразуем угол в кватернион
                q = euler2quat(
                    0.0, 0.0, th
                )  # returns (w, x, y, z) - такая у transforms3d специфика
                odom_msg.pose.pose.orientation.w = q[0]
                odom_msg.pose.pose.orientation.x = q[1]
                odom_msg.pose.pose.orientation.y = q[2]
                odom_msg.pose.pose.orientation.z = q[3]

                # Публикуем в топик /odom
                self.odom_pub.publish(odom_msg)

                # Одновременно шлём TF odom -> base_link
                t = TransformStamped()
                t.header.stamp = odom_msg.header.stamp
                t.header.frame_id = "odom"
                t.child_frame_id = "base_link"
                t.transform.translation.x = x
                t.transform.translation.y = y
                t.transform.translation.z = 0.0
                t.transform.rotation.w = q[0]
                t.transform.rotation.x = q[1]
                t.transform.rotation.y = q[2]
                t.transform.rotation.z = q[3]

                self.tf_broadcaster.sendTransform(t)

                # Для наглядности выведем в лог
                self.get_logger().info(f"ODOM: X={x:.3f} Y={y:.3f} Th={th:.3f}")
            else:
                # Можно выводить предупреждение, но чтобы не заспамить лог, сделаем debug
                self.get_logger().debug(f"Unknown line: {line}")

        except serial.SerialException as e:
            self.get_logger().error(f"Failed to read from serial: {e}")


def main(args=None):
    rclpy.init(args=args)
    node = RobotDriverNode()
    rclpy.spin(node)
    node.destroy_node()
    rclpy.shutdown()


if __name__ == "__main__":
    main()

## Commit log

2026-04-13 добавил рендеров и 3д моделей
2026-04-13 обновил 3д модели, добавил все метизы
    [Copy of DC-DC Step Down Buck Converter CC-CV 300W 20A^DCDC понижайка_turtlebot.SLDPRT]
2026-04-13 обновил 3д модели, добавил bambulab проект
    [turtlebot_bambu_project.3mf]
2026-04-13 добавил картинок
2026-04-14 добавил gif для footer
2026-04-14 добавил фото схемы подключения
2026-04-19 добавил картинку
2026-04-23 обновил 3д модель turtlebot .sldasm
    [Copy of DC-DC Step Down Buck Converter CC-CV 300W 20A^DCDC понижайка_turtlebot.SLDPRT]
2026-05-03 добавил видео работы лидара
2026-05-03 добавил фоток
2026-05-05 обновил 3д модель: - модель проверена на собираемость - изменена компоновка приборов внутри - убрана площадка под приборы - высота корпуса увеличена на 3 мм - крышка робота теперь магнитная - добавле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
    [turtlebot_bambu_project.3mf]
2026-05-05 добавил чертёж
2026-05-05 добавил фото сборки
2026-05-05 фото дефайсов для схем компонентов
2026-05-05 переименовал rickroll, чтобы не палили
2026-05-05 обновил 3д модель, добавил этикетки
2026-05-05 удалил дубли фото
2026-05-05 +1 фото
2026-05-06 добавил фото
2026-05-06 увеличил высоту корпуса esp32, опустил ниже крышку для проводов
2026-05-07 добавил step версию файлов моделей
2026-05-07 обновил крышку esp32
2026-05-08 обновил схему подключения, добавил type c порт, 4s зарядку, конденсаторы, резисторы
2026-05-08 добавил фото установленных резисторов и кондёров
2026-05-08 то же, что и в пред. коммите
2026-05-08 обнвоил фото резистора
2026-05-08 добавил фото pinout esp32
2026-05-08 добавил фото подключения esp32 к компу
2026-05-08 добавил фото pio
2026-05-08 инициализация Pio проекта для esp32
2026-05-08 фото для инструкций
2026-05-08 добавил расчёт одометрии в main.cpp
2026-05-09 обновил схему подключения
2026-05-09 добавил orbitty_carrier pinout
2026-05-10 обновил схему
2026-05-11 добавил: - музыку для загрузки - сейчас прошивка esp32 позволяет управлять движением робота через команды SET_SPEED 100 100 - добавлено управление светодиодной лентой
2026-05-11 изменения: - поменял название папок с кодом для jetson\raspberry (ecu) и esp32 (mcu) -добавил systemd unit файлы для звуков включения робота и выключения
2026-05-11 обновил схему подключения - led лента теперь подключается к 13 пину у esp32
2026-05-11 добавил: - настройку ttyTHS2 при запуске сервиса tb_on_powerup - добавил возможность управления светодиодной лентой с микроконтроллера
2026-05-11 добавил README.md для esp32
2026-05-11 добавил намётки web интерфейса для низкоуровневого управления роботом
2026-05-12 разделил сборки на TX2 и NX версии основных вычислителей
    [turtlebot_nx.SLDASM, turtlebot_tx2.SLDASM]
2026-05-12 сделал actions, который должен собирать артифакт для jetson
2026-05-12 изменения: - добавид go2rtc бинарь - конфиг для него же - новые серивсы
2026-05-12 изменения: - кнопки для управления колёсами можно нажимать из браузера без кнопок с клавиатуры - снопка стоп воспринимает нажатия пробела - для изменения цвета подсветки теперь не надо нажимать "прим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
2026-05-13 Изменения: - Добавили вкладку состояния робота в веб-интерфейс: нагрузка Jetson, память, температура, заряд батареи, напряжение, ток потребления и время работы системы. - Добавили выключение turtlebo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
2026-05-13 правка actions
2026-05-13 доабвил фото зарядного порта
2026-05-13 доабвил фото esp32 с отверстиями
2026-05-13 доабвил фото web интерфейса
2026-05-15 Добавлен ros2 в docker! Кроме этого: - переместил config в src/ecu - добавил установку docker compose - добавил nginx сервер - добавлена команда SET_ROBOT_VELOCITY для esp32
2026-05-15 добавил requirements.txt
2026-05-15 изменил права пользователя в контейнерах
2026-05-15 добавил ros2 пакеты robot_odom и robot_control
2026-05-17 добавил автозапуск нод при старте контейнера
2026-05-17 - добавил сборку ноды для лидара - переименовал ws -> ros2_ws - добавил ноду, которая будет запускать все остальные ноды
2026-05-20 обновил 3д модели: увеличил высоту лидара по отношению к крышке
    [turtlebot_tx2.SLDASM]
2026-05-20 Кратко по функциональным изменениям текущего diff:
    - Web backend больше не ходит напрямую в UART. Теперь `src/ecu/main.py` общается с ROS2-контейнером через `docker exec`.
    - Команды с фронтенда (`SET_LED`, `SET_COEFF`, `SHUTDOWN`, `SET_WHEELS_SPEED`) публикуются в ROS2 topics, а не пишутся сразу в serial.
    - Убрана задержка от `ros2 topic pub --once`: backend держит постоянный ROS publisher-процесс внутри контейнера и отправляет команды через stdin.
    - Телеметрия ESP32 т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
2026-05-20 переименовал main.py -> web_control_center.py
2026-05-20 добавили кнопку перезагрузки jetson
